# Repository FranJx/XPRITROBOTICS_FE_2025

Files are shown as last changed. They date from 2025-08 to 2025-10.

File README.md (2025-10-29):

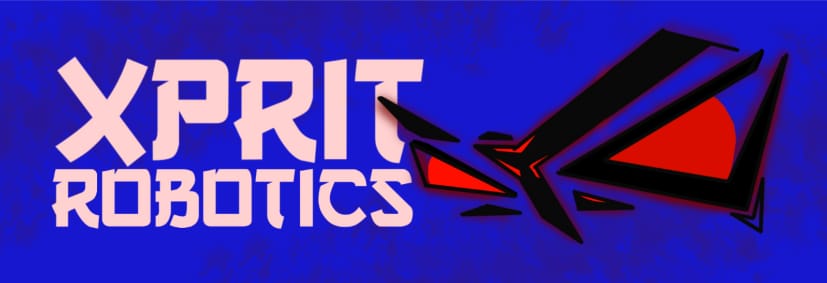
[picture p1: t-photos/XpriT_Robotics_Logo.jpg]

# - XpriT Robotics – WRO 2025 Future Engineers
## Introduction

We are **XpriT Robotics**, a team dedicated to creating robotics projects for participation in various competitions. Our main focus is on education and knowledge sharing, using challenges as opportunities to grow and inspire others. 
Through our projects, we explore robotics and engineering challenges to expand our skills, creativity, and experience.
For this competition, we aim to design a robot capable of avoiding obstacles, completing a circuit, and parking in a designated area.

This repository contains the engineering materials of our autonomous vehicle model developed by **XpriT Robotics**, competing in the **WRO 2025 Future Engineers** category. It includes source code, documentation, design files, photos, schematics, and a driving demonstration video.
---
## Repository Structure

* [**Bill Of Materials**](#bill-of-materials) - Bill Of all the Materials we used in this project covering mechanical pieces, 3D printed pieces, components and electronics.
* [**Step by Step Asemble Guide**](#step-by-step-asemble-guide) – This section provides a step-by-step guide, covering everything from assembling the parts to uploading the code and configuring some of the components.
* [**Software and Code Explanation**](#software-and-code-explanation) – This section provides a step-by-step guide, covering everything from assembling the parts to uploading the code and configuring some of the components.
* [**Engineering Journal**](#engineering-journal) – A journal where describes the decisions we made along the project.
---
## Folders Content

* [**T-photos**](t-photos/) – Two team photos: a formal one and a funny group shot.
* [**R-photos**](r-photos/) – Six images of the vehicle: front, back, left, right, top, and bottom.
* [**Video**](Videos/) – A Video of the robot driving.
* [**Schemes**](Schemes/) – Electromechanical schematic diagrams showing how components connect. 
* [**3Dmodels**](3Dmodels/) – Files for 3D-printed pieces of the robot
* [**Code**](Code/) – Robot code for Arduino Nano
---
## Meet the Robot
We proudly present **Kmioncito**, our robot for the WRO Future Engineers 2025 challenge.  
Its name, derived from the Spanish word *“camioncito”* (“little truck”), reflects its compact, sturdy design and the friendly personality we associate with our creations.
Kmioncito represents the result of months of teamwork, testing, and design iteration — combining **3D-printed mechanics**, **intelligent electronics**, and **optimized software** for autonomous navigation and obstacle avoidance.
### Robot Pictures From All Angules

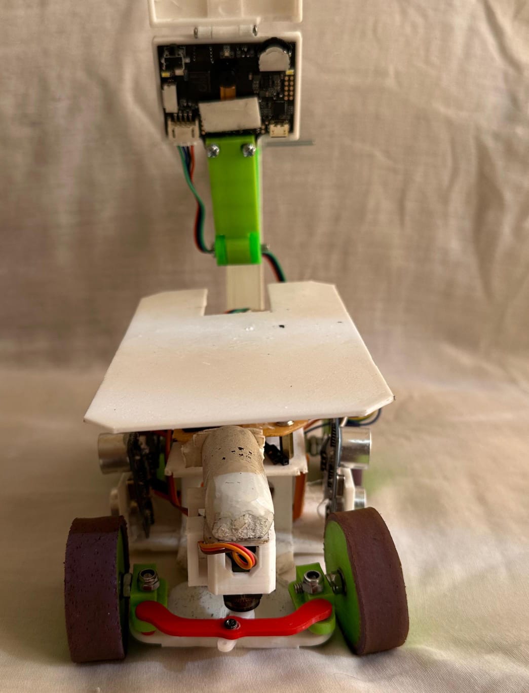
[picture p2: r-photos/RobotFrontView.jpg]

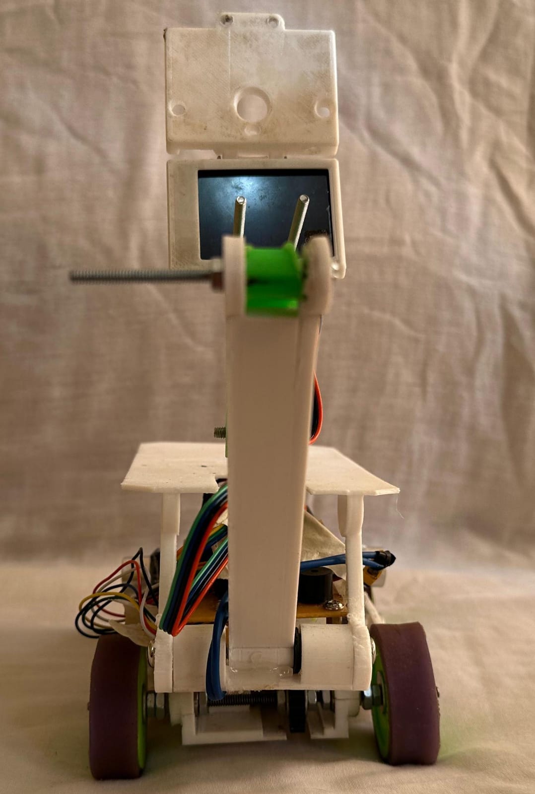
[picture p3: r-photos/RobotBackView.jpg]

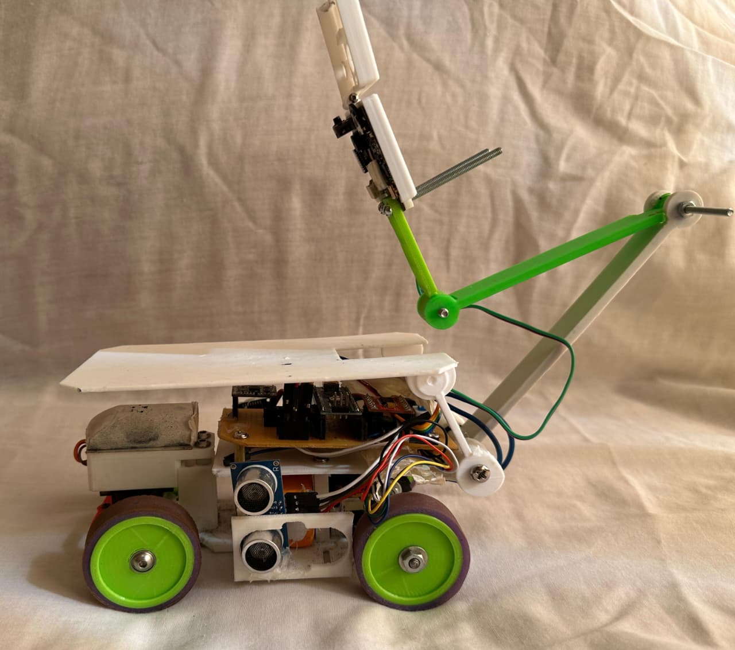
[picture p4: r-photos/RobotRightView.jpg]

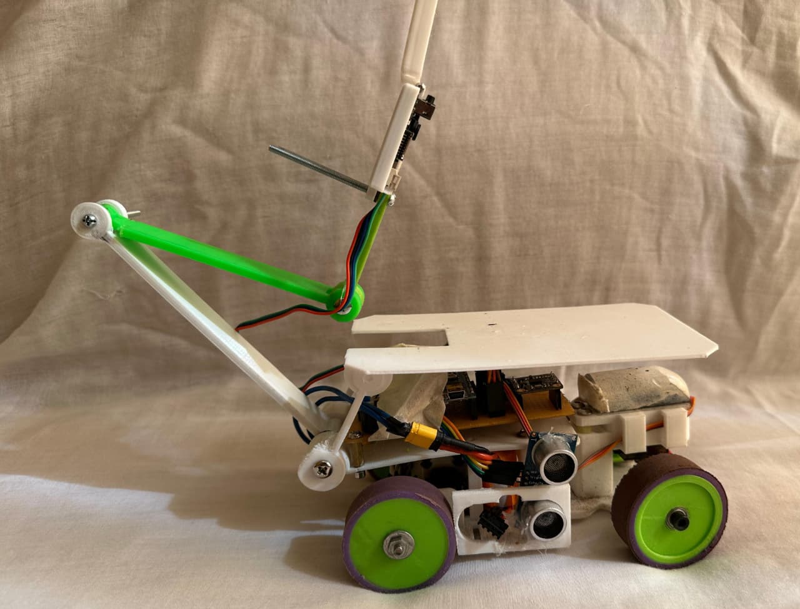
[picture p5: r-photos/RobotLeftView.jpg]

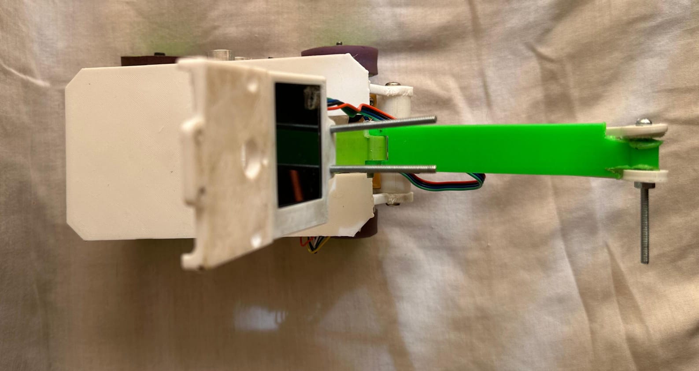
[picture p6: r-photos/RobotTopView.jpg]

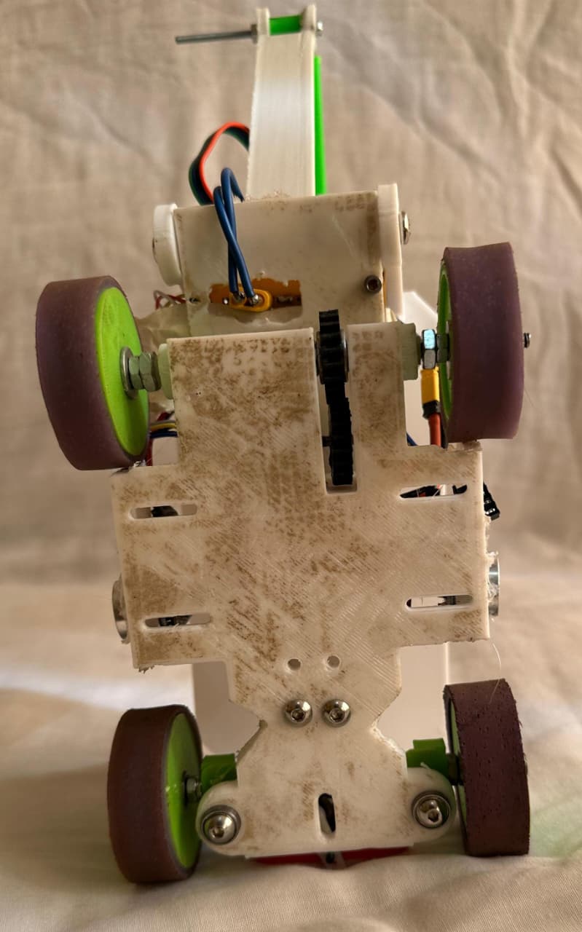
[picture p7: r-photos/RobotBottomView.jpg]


You can explore the mechanical, electronic, and software design in the sections below for detailed implementation.

---
## Bill Of Materials

### Electronics:
* 1x Arduino Nano. (Old Bootloader)
* 1x TB6612FNG
* 1x Diode
* 1x LN7805
* 1x Capacitor 100uf
* 1x Push Button
* 1x Push Interruptor
* 1x Active Buzzer

### Components and Sensors:
* 3x Ultrasonic Sensor HC-SR04
* 1x DFrobot Huskylens AI Camera
* 1x BNO055 gyroscope
* 1x MG90S servomotor
* 1x DC motor N20 with Encoder

### Mechanical and 3D printed Pieces:

* 6x Bearings (4mm interior and 10mm exterior)
* 8x Nuts
* 8x Washers
* 1x Threaded rod
* Every 3D model in the [**3Dmodels**](3Dmodels/) folder
---
## Project Overview

### Mechanical Design

The robot’s mechanical system was developed with a focus on **compactness, stability, and maneuverability**. It consists of two main subsystems: the **Ackermann steering mechanism** and the **traction system**.

#### Ackermann Steering System
- The steering is based on a simplified **Ackermann geometry**, implemented with a 3D-printed mechanism.  
- A **servo motor** (MG90S) controls the main steering linkage.  
- The linkage transmits motion to two pivoting axles, allowing the front wheels to turn at different angles during curves.  
- This ensures that the inner wheel follows a tighter turning radius than the outer wheel, improving maneuverability and reducing tire slip.  

**Advantages of this design:**
- Simple to manufacture with minimal mechanical parts.  
- Easy to assemble and maintain.  
- Lightweight, compact, and optimized for small turns within the competition field.  

#### Traction System
- The rear wheels are powered by **N20 DC motors with encoders**, providing both propulsion and feedback for precise distance control.  
- The motors transmit motion through a **1:1 gear ratio system**, using custom **resin-printed gears** mounted on a metal axle.  
- The axle drives both rear wheels simultaneously, ensuring consistent forward movement.  

**Advantages of this design:**
- High precision thanks to the encoders.  
- Strong and reliable traction for both straight paths and turns.  
- Custom gears in resin are resistant to wear compared to standard PLA 3D prints.  

#### Chassis
- The chassis is a **compact 3D-printed frame** with integrated mounts for electronics, sensors, and the steering system.  
- The design evolved from early modular prototypes to a single-piece chassis, reducing assembly complexity and improving robustness.  
- Includes a **dedicated adjustable mount for the HuskyLens camera**, allowing flexible positioning during testing and competition.  

### Electronics Design

The electronic system of the robot integrates all the sensors, actuators, and controllers required for autonomous navigation.  
A complete circuit schematic is included in the repository under the folder: [**Schematics**](Schematics/).

#### Microcontroller
- **Arduino Nano** serves as the main controller.  
- It processes sensor inputs, executes navigation algorithms, and controls actuators.  
- Connected via USB for programming and debugging.

#### Motor Driver
- **TB6612FNG dual motor driver**.  
- Used to drive the N20 DC motors with PWM speed control.  
- Provides reliable performance with low heat dissipation.

#### Motors and Actuators
- **2x N20 DC motors with encoders** (rear traction).  
- **1x MG90S servo motor** for the Ackermann steering mechanism.  
- Encoders provide feedback for distance and turning accuracy.

#### Sensors and Vision
- **2x HC-SR04 ultrasonic sensors** (left and right sides).  
  - Used for wall detection and corridor navigation.  
- **BNO055 IMU sensor**.  
  - Provides heading information for orientation correction and PID stabilization.  
- **HuskyLens AI Camera**.  
  - Detects obstacles (red and green cubes) and provides position data for avoidance maneuvers.  

#### Power Supply
- Powered by a **3S Li-Po battery (11.1V)**.  
- Voltage is regulated to supply 5V for the Arduino and sensors, and motor driver receives direct battery voltage.  
- Common ground is shared across all components.

#### Additional Components
- **Buzzer** connected to the Arduino, used as a feedback indicator for distance readings
---
## Step-by-Step Assembly Guide

This section provides a detailed guide on how to assemble the robot, from the mechanical systems to the electronics, camera setup, and software configuration.  

### 1. Steering System
**Required parts:** `Lower Chassis`, `Left Joint`, `Right Joint`, `Tires`, `Steering Axle`

1. Insert a bearing into each circular slot located at the front ends of the `Lower Chassis`.  
2. Place the `Left Joint` and `Right Joint` on top of the bearings, aligning them correctly with their sides.  
3. From the bottom, insert a screw through the bearing and secure it with a nut on top.  
4. Attach the `Tires` to the joints by inserting their axles into the wheel slot of each joint.  
5. Insert a screw through each wheel and joint, then fasten it with a nut on the opposite side. Repeat for both wheels.  
6. Mount the `Steering Axle` across the front of the joints, pressing it into the designated holes so it fits securely.  

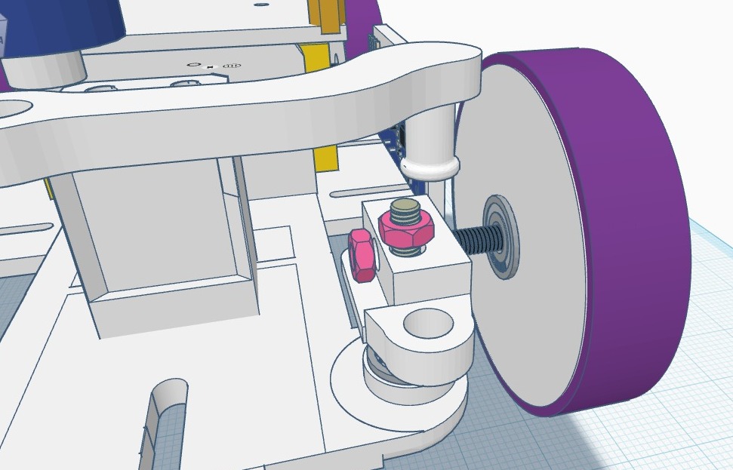
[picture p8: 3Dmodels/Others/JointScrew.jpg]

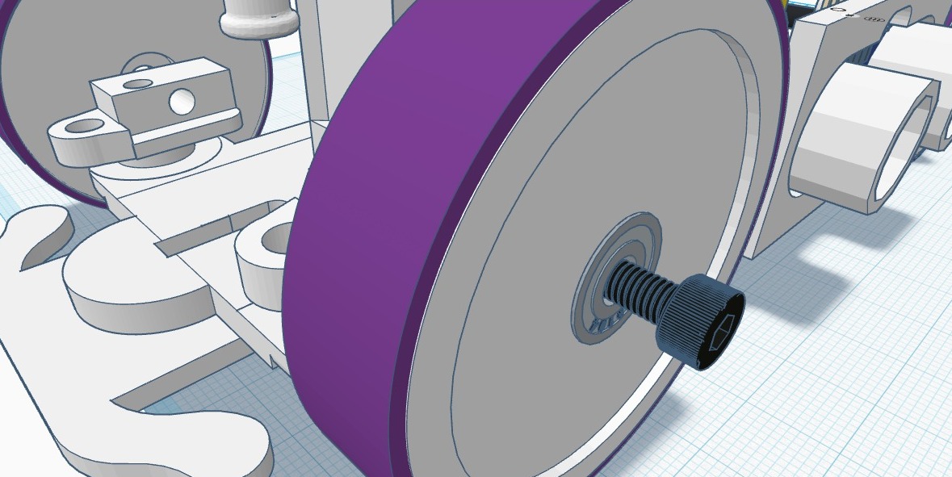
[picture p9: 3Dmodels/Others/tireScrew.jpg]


---

### 2. Servo Motor
**Required parts:** `Servo Motor Base`, `Servo Motor Holder`  

1. Place the `Servo Motor Base` slightly behind the steering system, aligning it with the four mounting holes in the chassis.  
2. Insert screws from the bottom of the chassis and secure them with nuts.  
3. Place the servo motor on top of the base.  
4. Fix it in place by mounting the `Servo Motor Holder` above it.  
5. Ensure the servo arm is aligned with the small hole at the center of the `Steering Axle`. Secure it with a screw.  

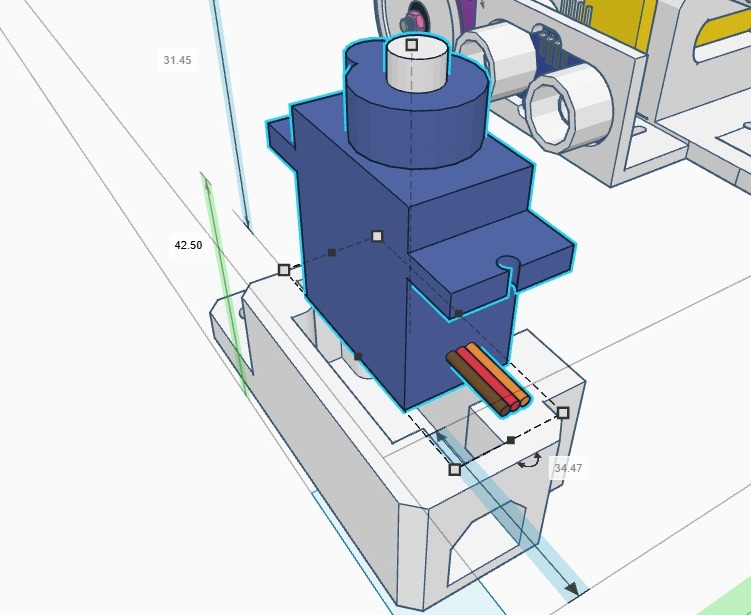
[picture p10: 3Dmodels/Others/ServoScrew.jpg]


---

### 3. Traction System
**Required parts:** `Rear Axle Gear`, `Motor Gear`, threaded rod, bearings, wheels, nuts and locknuts  

1. Locate the rear section of the chassis where the N20 motor mount and elongated slot are positioned.  
2. Mount the N20 motor into its slot and attach the `Motor Gear` to its shaft.  
3. Insert a bearing into each side wall hole of the chassis, pressing them firmly.  
4. Slide the threaded rod through the first bearing.  
5. Mount the `Rear Axle Gear` on the rod, then slide the rod through the second bearing. Both ends should extend slightly outside the chassis.  
6. Place a nut and a locknut on each side of the rod to secure it.  
7. Attach the wheels on both ends of the rod, leaving a small part of the rod exposed. Fix them with an additional nut on each side.  
8. Make sure the `Motor Gear` and the `Rear Axle Gear` are properly aligned so the motor can drive the axle.  

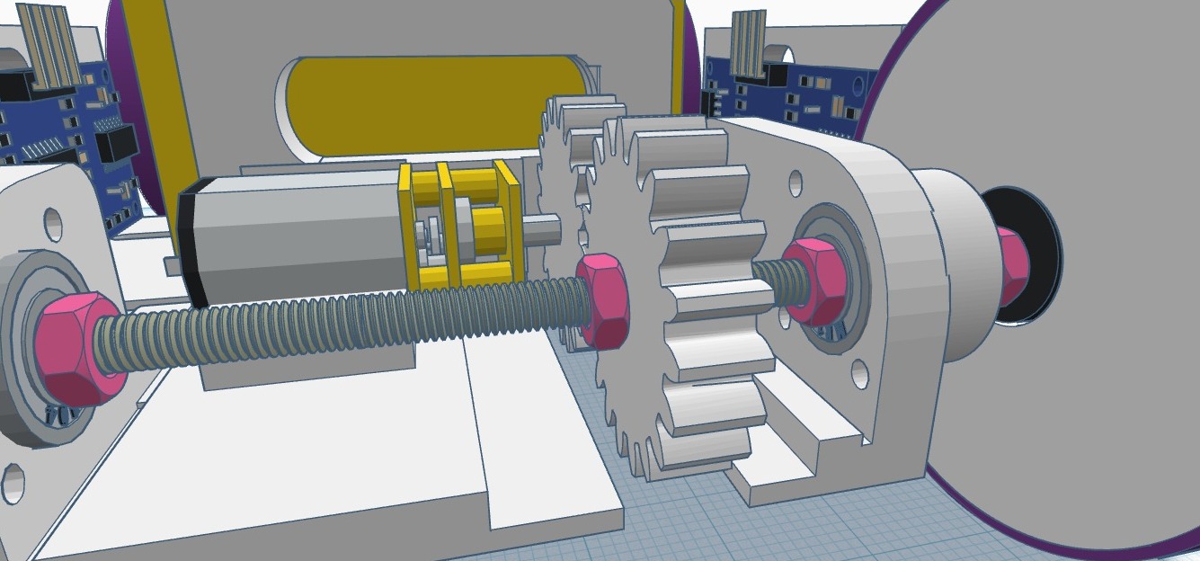
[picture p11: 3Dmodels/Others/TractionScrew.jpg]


---

### 4. Electronics
**Required part:** `Upper Chassis`  

1. Place the `Upper Chassis` above the main chassis, aligning its screw holes with the rectangular pillars.  
2. Secure it with screws and nuts.  
3. Mount the perforated PCB board on top of the `Upper Chassis`.  
4. Position the battery between the two lower pillars, underneath the PCB board.  

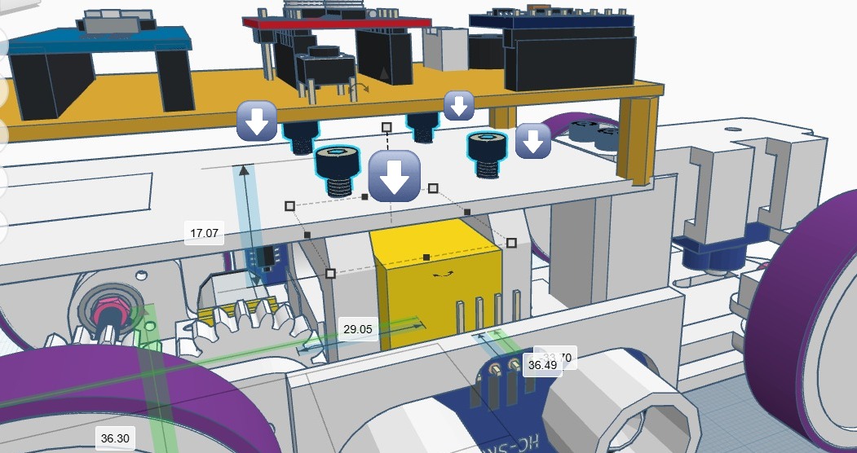
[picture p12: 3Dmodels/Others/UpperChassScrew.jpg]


---

### 5. Camera Support
**Required parts:** `PCB Ceiling`, `Lower Arm`, `Upper Arm`, `Camera Support`  

1. Attach the `PCB Ceiling` by aligning its arms with the `Upper Chassis`.  
2. Mount the `Lower Arm` in the middle and fasten it with screws.  
3. Connect the `Upper Arm` to the end of the `Lower Arm` and secure it.  
4. Attach the `Camera Support` at the end of the arm.  
5. Place the **HuskyLens camera** onto the support and secure it with screws.  


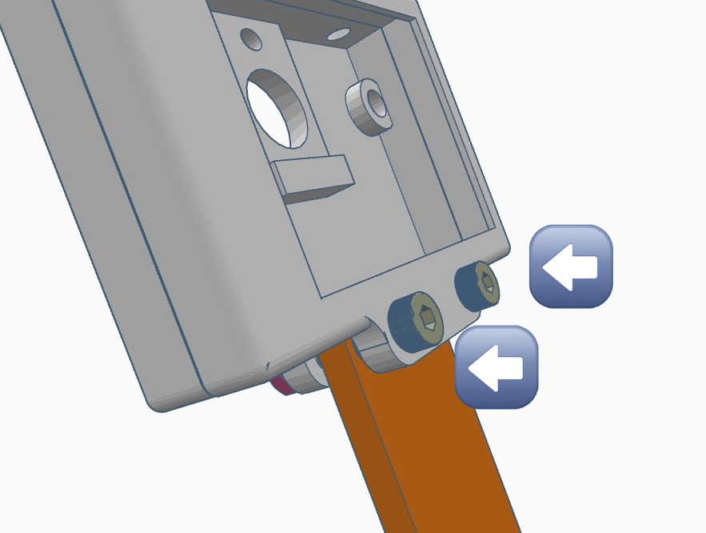
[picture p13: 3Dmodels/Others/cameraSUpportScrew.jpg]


---

### 6. Uploading the Code

1. Connect the **Arduino Nano** to your computer using a USB Mini-B cable.  
2. Open the **Arduino IDE** and load the provided code from this repository.  
3. Click **Upload** and wait until the IDE confirms `Upload complete`.  
4. Disconnect the cable after uploading.  

---

### 7. HuskyLens Configuration

1. Power on the robot (via battery or USB). The HuskyLens display will turn on.  
2. Use the dial to navigate through the HuskyLens interface.  
3. Go to **Settings → Communication Mode** and select **I2C**.  
4. Return to the main menu and select **Color Recognition** mode.  
5. Place the green and red obstacles in front of the camera.  
6. Hold the button next to the dial to train the color recognition.  
7. Repeat for both obstacles until the camera assigns **ID:1** to one color and **ID:2** to the other.  

---

At this point, your robot is fully assembled, configured, and ready for testing.

## Software and Code Explanation

The robot’s code was designed to combine stability, reliability, and adaptability during the challenge. Its behavior can be summarized in four main stages:
Straight Navigation with Gyroscope Correction

The robot advances forward while continuously correcting its heading using the BNO055 gyroscope. If it drifts from the desired orientation, the servo adjusts to bring it back on course, ensuring consistent straight-line movement.

### Corridor Turns with Ultrasonic Sensors

When one of the ultrasonic sensors detects open space to the left or right, the robot executes a precise 90° turn in that direction. The encoder ensures that the turn is completed fully by measuring wheel pulses, preventing incomplete or unstable turns.

### Object Avoidance with Vision (HuskyLens)

If the HuskyLens camera detects a red or green cube, the robot immediately prioritizes avoidance. It steers away from the object’s position and moves forward until the obstacle is no longer detected. Once clear, it recenters the servo and resumes its planned trajectory.

### Parking

At the beginning of the run, Kmioncito starts inside the parking area.  
Using the HuskyLens AI camera, it scans the first quadrant of its field of view to check if it can detect the pink color (ID:3) that represents the parking zone.  
Once the camera identifies this color, the robot determines its initial position and exits the parking area by moving toward the opposite direction of the detected wall.

As the robot leaves the zone, it uses its motor encoder to measure the distance traveled.  
If the distance exceeds one meter, the robot concludes that the parking zone is located at the rear side of the circuit.  
If it travels less than one meter, the robot determines that the parking zone is at the front side.  
This information is saved as a reference variable for the final part of the challenge.

After this step, Kmioncito continues its normal navigation, avoiding obstacles and following the circuit path.  
It ignores the parking area until the final stage of the run.

When it is time to park, the robot recalls the previously stored information about whether the parking zone is in the front or rear part of the field.  
It then moves toward that area, aligning its rear side with the front edge of the parking zone.  
Once aligned, it performs a 90° turn to face the parking area and starts reversing.  
While moving backward, the robot uses its ultrasonic sensors to detect the wall behind it.  
As soon as the wall is detected, it moves slightly forward, performs another 90° turn, and finally positions itself parallel to the wall, completing the parking maneuver.

### Completion of the Route

After a predefined number of turns, the robot drives forward for an additional encoder-based distance and then stops completely. This guarantees that the robot finishes the run in a controlled and repeatable manner.

---
## Engineering Journal

Here's a link to our Engineering Journal: 

https://docs.google.com/document/d/1Jj0EOl-bdzsbxWS2QZuM9kGpr0p5ontHu1RqVm_BO6E/edit?usp=sharing
---
## Demonstration Videos

https://youtu.be/O4qihtPzeu4?si=GkjUZdUodrYpeQK6
---

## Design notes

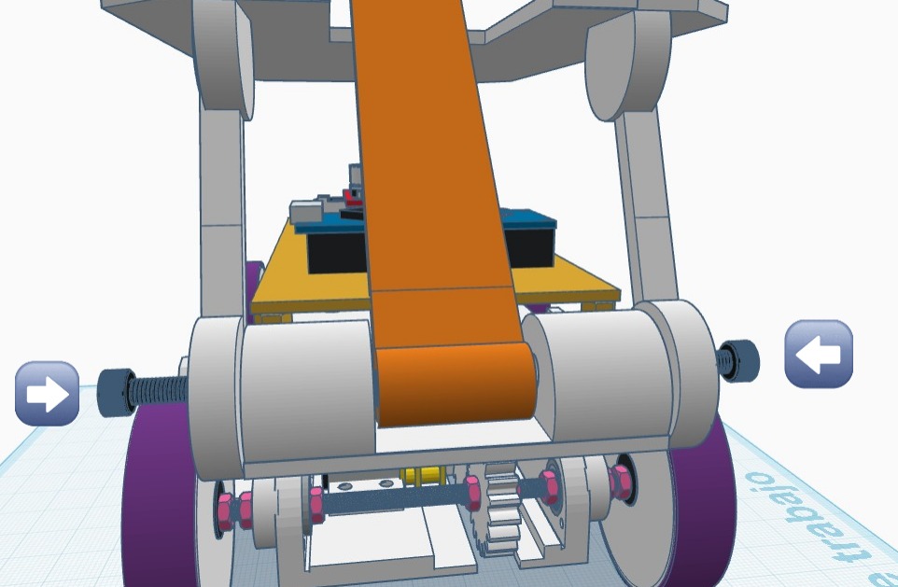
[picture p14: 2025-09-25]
3Dmodels/Others/pcb ceiling screw.jpg

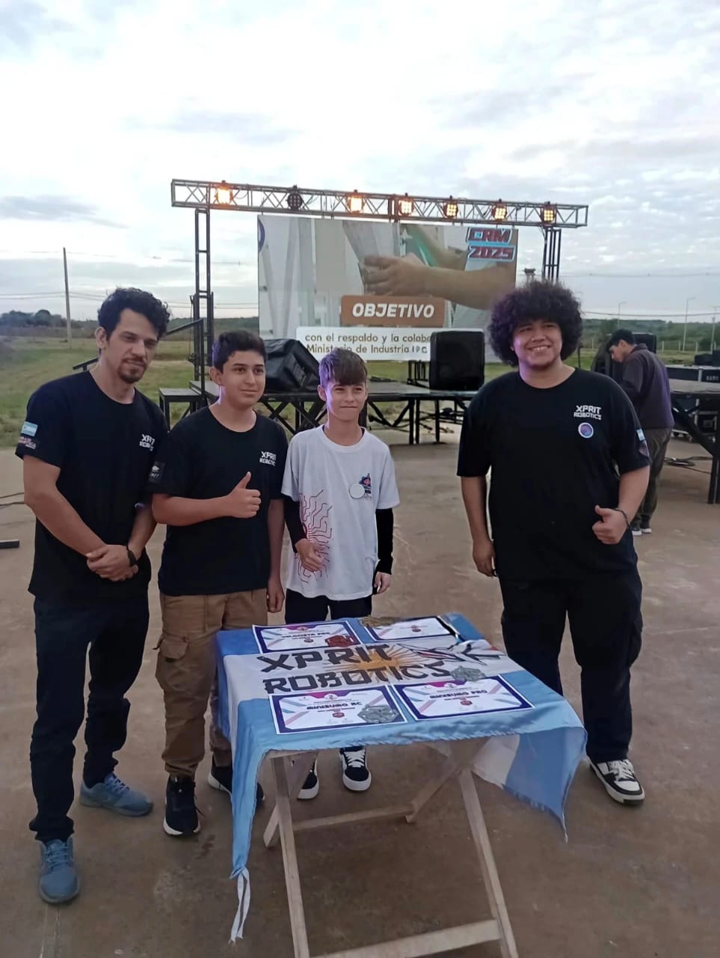
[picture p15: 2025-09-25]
t-photos/Imagen de WhatsApp 2025-09-25 a las 15.16.17_4187245f.jpg

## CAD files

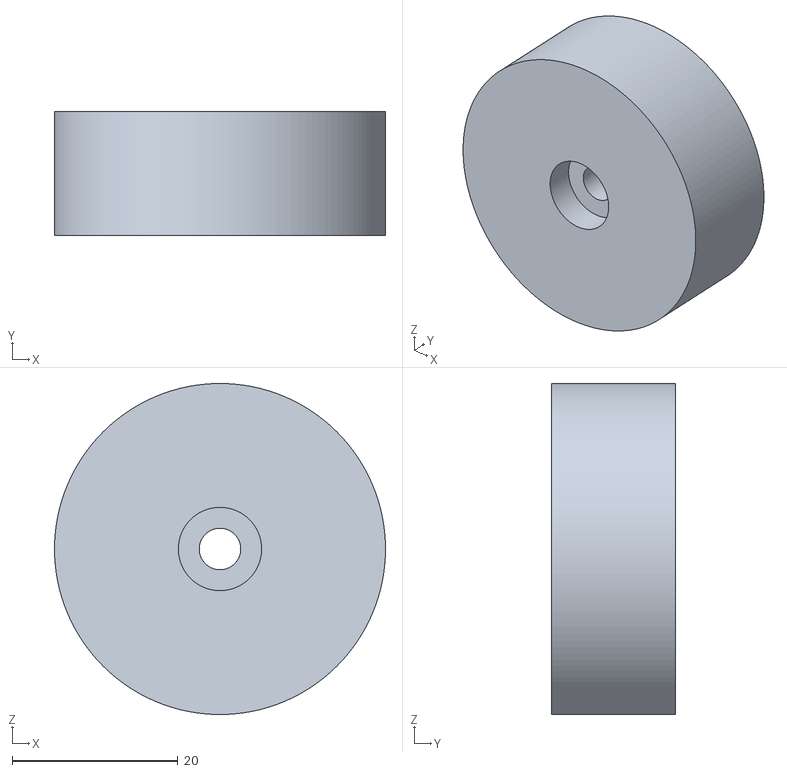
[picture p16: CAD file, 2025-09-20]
3Dmodels/rinx4.stl
40.0 x 15.0 x 40.0

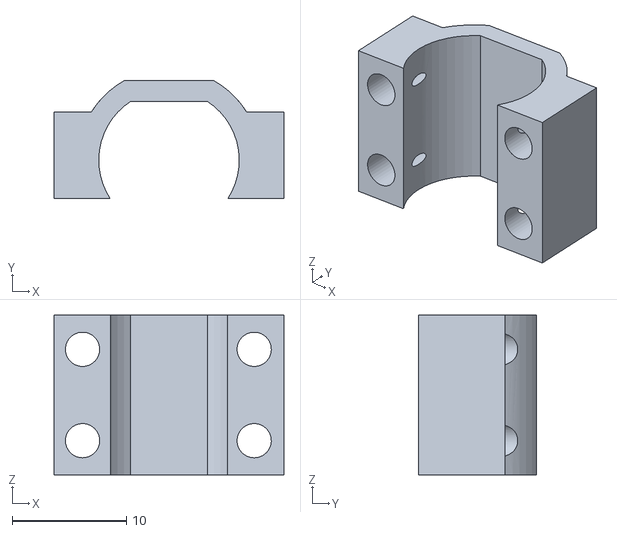
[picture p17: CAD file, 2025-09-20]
3Dmodels/bracket n20.STL
20.1 x 10.4 x 14.0

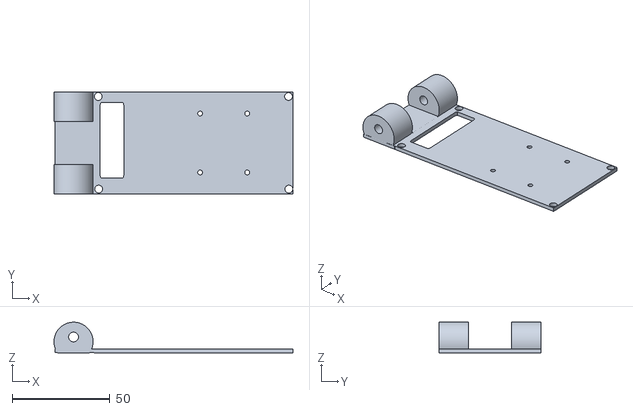
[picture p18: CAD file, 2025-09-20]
3Dmodels/soporte placa y cam.stl
122.4 x 52.2 x 15.7

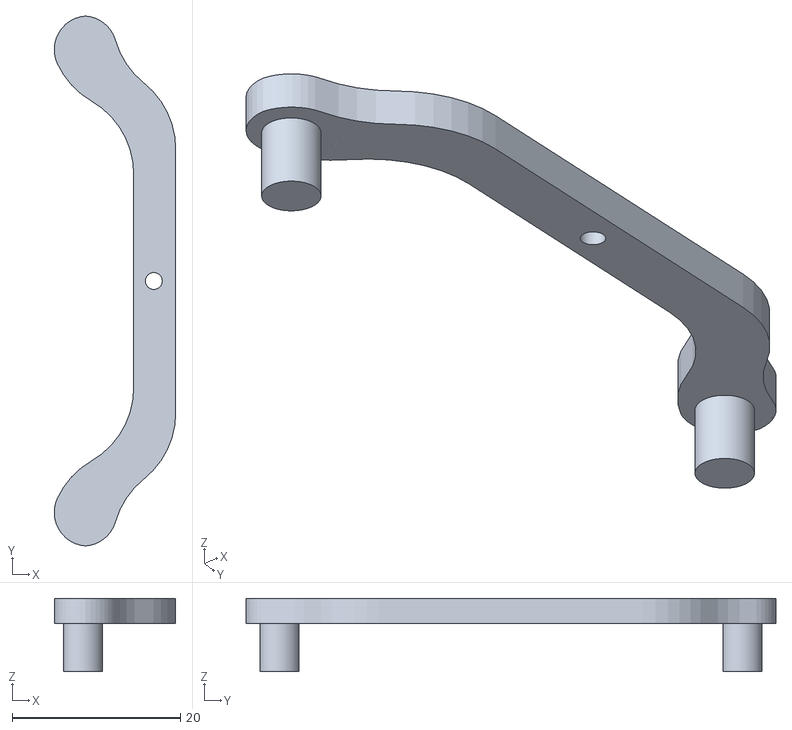
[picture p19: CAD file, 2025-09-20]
3Dmodels/cremallera.stl
14.4 x 63.0 x 8.70

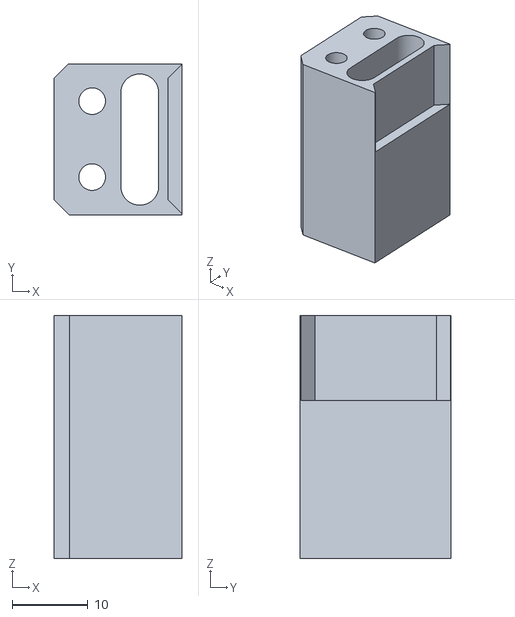
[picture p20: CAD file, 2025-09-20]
3Dmodels/Sizzling Rottis (6).stl
16.8 x 19.9 x 32.0

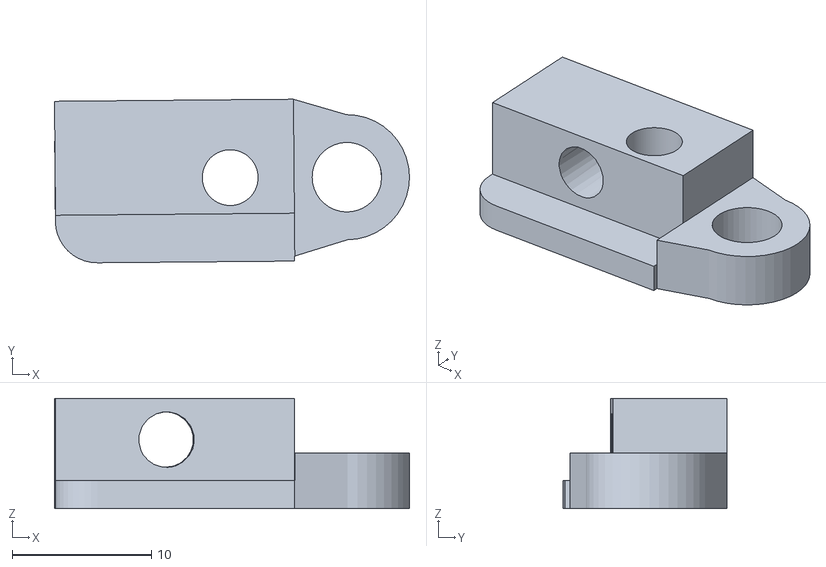
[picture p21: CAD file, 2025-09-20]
3Dmodels/rotulas (1).stl
25.5 x 11.8 x 7.91

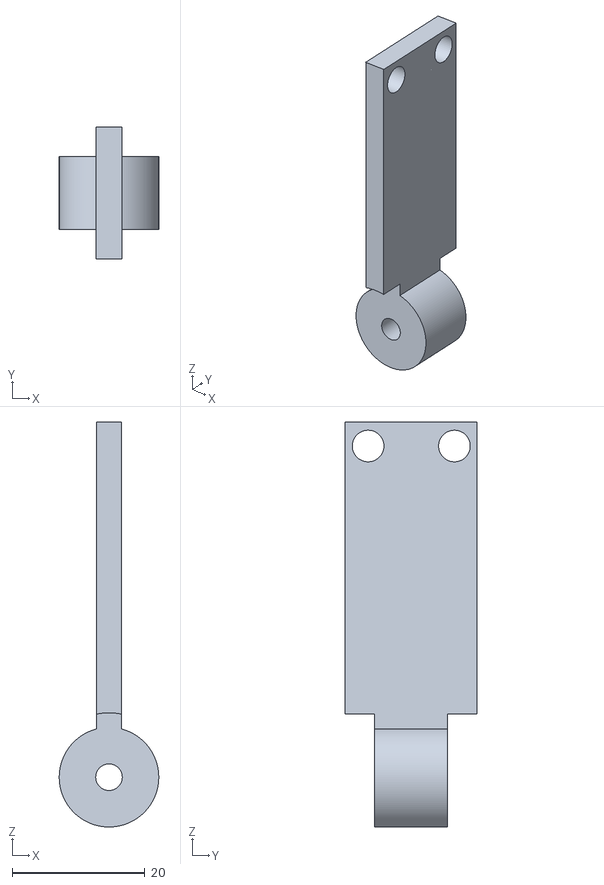
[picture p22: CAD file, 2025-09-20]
3Dmodels/brazocamsup.stl
15.0 x 19.9 x 61.0

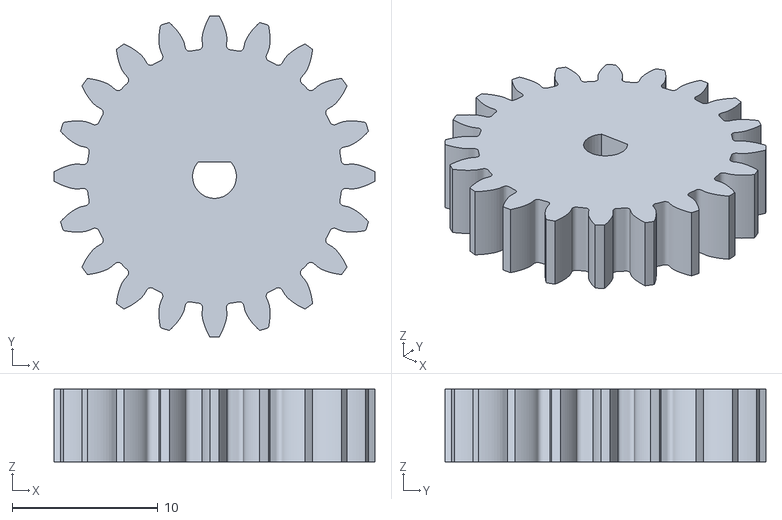
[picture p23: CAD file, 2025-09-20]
3Dmodels/engranajemotor.stl
22.0 x 22.0 x 5.00

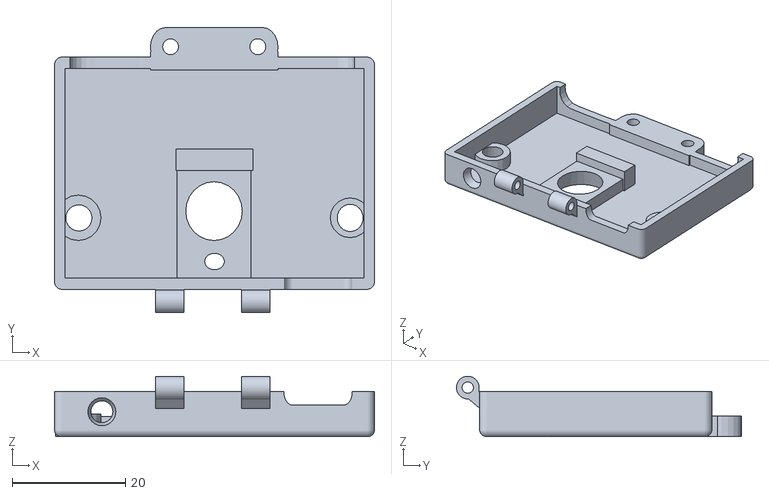
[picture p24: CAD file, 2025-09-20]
3Dmodels/Huskylens Cover_front.stl
56.4 x 50.2 x 10.7

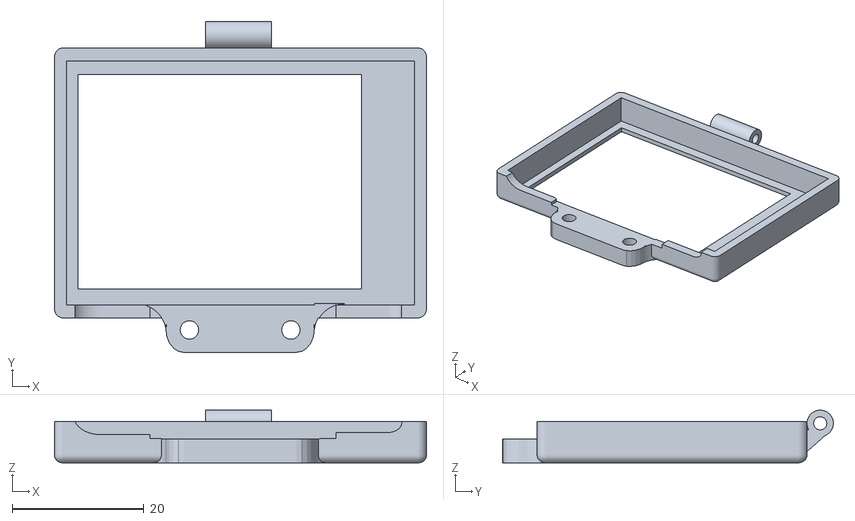
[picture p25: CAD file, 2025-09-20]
3Dmodels/Huskylens Cover_back.stl
56.4 x 50.1 x 8.00

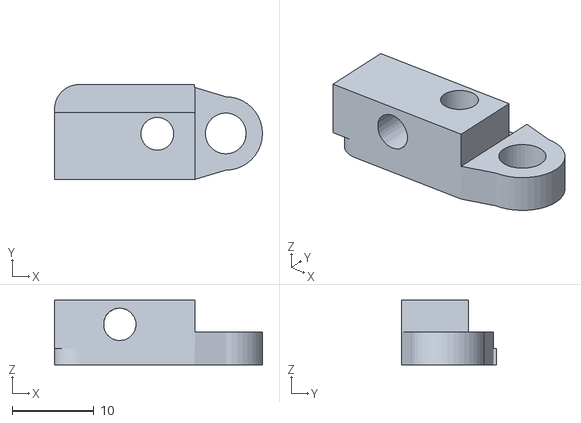
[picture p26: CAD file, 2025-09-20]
3Dmodels/rotulas (2).stl
25.5 x 11.6 x 7.91

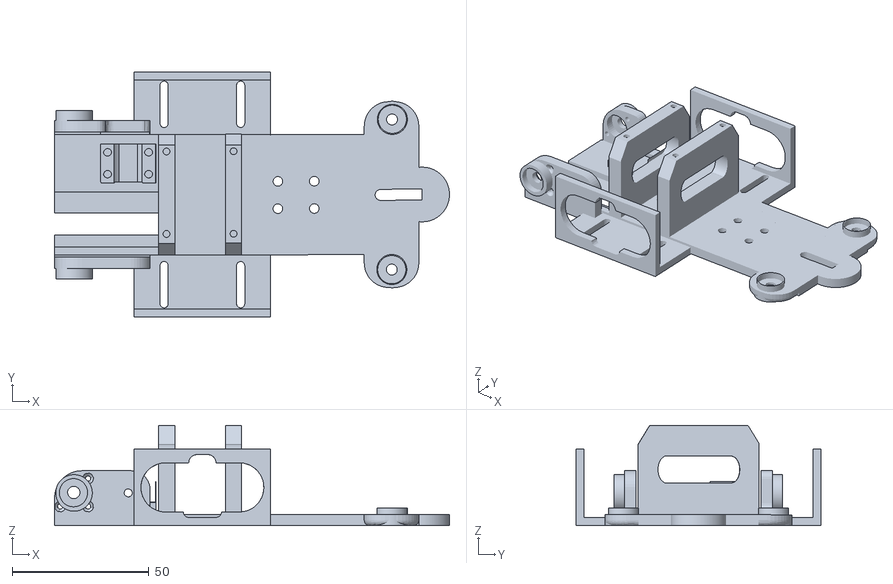
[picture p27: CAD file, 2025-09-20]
3Dmodels/chasis (2).stl
144.5 x 89.6 x 36.7

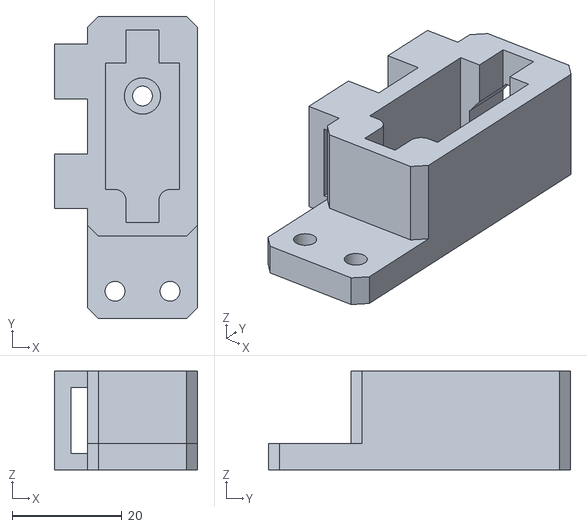
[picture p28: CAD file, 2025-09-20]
3Dmodels/servo_hold_bottom_1_lineguide.stl
26.0 x 55.0 x 18.0

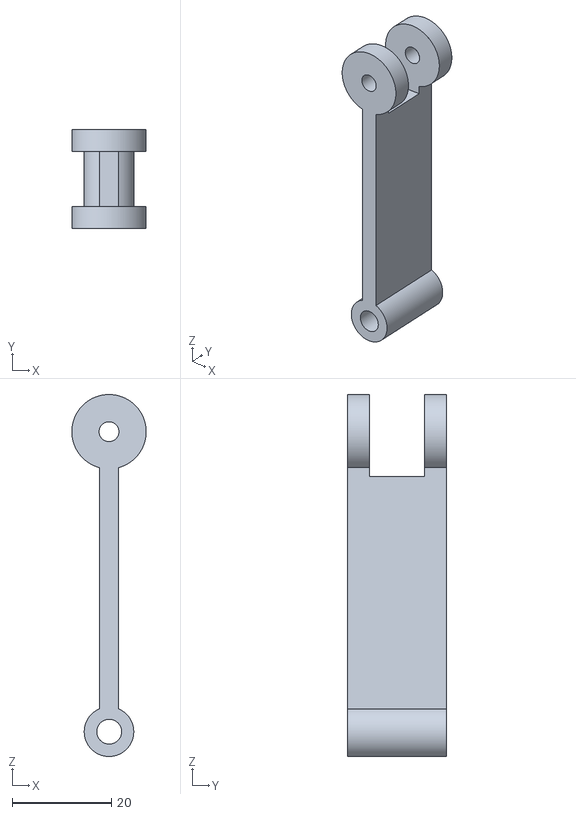
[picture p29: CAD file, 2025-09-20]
3Dmodels/brazocam inf.stl
15.0 x 20.0 x 73.0

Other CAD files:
3Dmodels/engranajeeje.stl

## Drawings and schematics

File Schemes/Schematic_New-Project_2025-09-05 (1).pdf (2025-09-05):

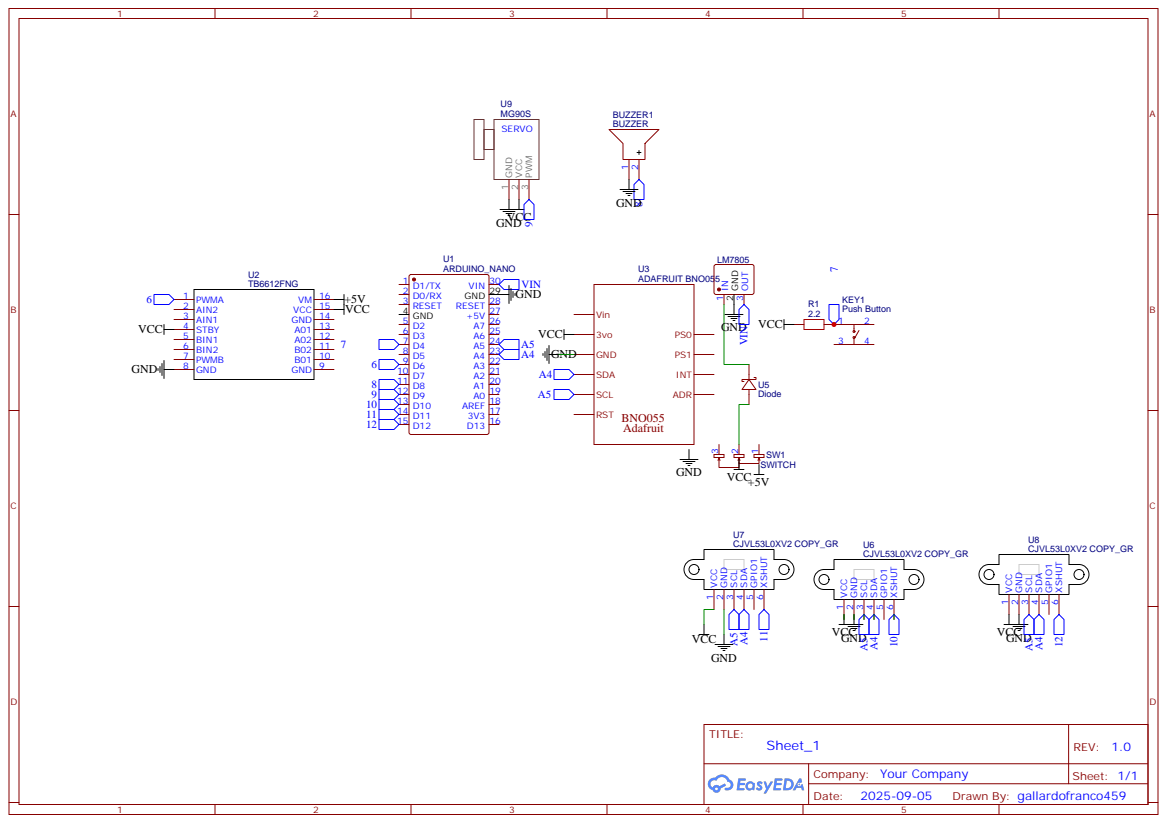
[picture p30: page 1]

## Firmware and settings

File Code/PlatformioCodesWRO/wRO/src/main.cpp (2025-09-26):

#include <Arduino.h>
#include <Servo.h>
#include <Adafruit_Sensor.h>

#include <Adafruit_BNO055.h>
#include <Wire.h>
#include "huskylens_utils.h"

#define TRIG_IZQ A2
#define ECHO_IZQ A3
#define TRIG_DER A0
#define ECHO_DER A1
#define MA1 5
#define MA2 4
#define PWM 6
#define SERVO_PIN 9
#define ENCODER_A 3

Servo direccion;
Adafruit_BNO055 bno = Adafruit_BNO055(55);
float Kp = 2.1, Ki = 0.0, Kd = 0.80;
int centroServo = 90;
int limAng = 50;
const int pwmRecto = 93;
const int pwmEsquiva = 120; // Velocidad especial al esquivar (ajusta a gusto)
const int pwmGiro = 165;
const int giros = 12;
int girosActuales = 0;
bool avanzandoExtra = false;
long encoderFinalExtra = 0;
const long PULSOS_EXTRA = 1000; // Pulsos extra tras el último giro
int lado = 0; // 0 = no definido, 1 = izquierda, 2 = derecha
const int distGiro = 30; // Distancia mínima para girar (cm)

bool velocidadVariable = false; // Si es false, siempre usa velocidad crucero
const int velocidadCrucero = 120; // 130    Ajusta este valor según tu necesidad
bool velocidadProporcionalServo = true; // NUEVO: Flag para velocidad proporcional al giro del servo
const int velocidadMinCrucero = 40;     //  52    Velocidad mínima en modo crucero proporcional

volatile long encoderCount = 0;
int orientation = 0;
float setpoint = 0;
bool bloqueado = false;
long pulsosBloqueo = 0;
int pulsosBloqueoUsar = 700;
const long PULSOS_GIRO = 900; // Bloqueo normal
const long PULSOS_GIRO_ESQUIVA = 1800; // Bloqueo si esquivó antes del giro
long ultimoEsquivaEncoder = -10000; // Para registrar el último encoder de esquiva
const long PASOS_ANTES_GIRO = 500;

long medirDistancia(int trigPin, int echoPin) {
  digitalWrite(trigPin, LOW);
  delayMicroseconds(2);
  digitalWrite(trigPin, HIGH);
  delayMicroseconds(10);
  digitalWrite(trigPin, LOW);
  long duracion = pulseIn(echoPin, HIGH, 25000);
  long distancia = duracion * 0.017;
  if (distancia == 0) distancia = 4000;
  return distancia;
}

void encoderISR() {
  encoderCount++;
}

void bloquearHeading(long pulsos) {
  bloqueado = true;
  pulsosBloqueo = encoderCount + pulsos;
}

void actualizarOrientation(int delta) {
  orientation += delta;
  if (orientation < 0) orientation = 3;
  if (orientation > 3) orientation = 0;
  setpoint = orientation * 90;
  bloquearHeading(pulsosBloqueoUsar);
}

void setup() {
  pinMode(8, OUTPUT); // buzzer
  Serial.begin(9200);
  pinMode(MA1, OUTPUT);
  pinMode(MA2, OUTPUT);
  pinMode(PWM, OUTPUT);
  pinMode(ENCODER_A, INPUT_PULLUP);
  direccion.attach(SERVO_PIN);
  direccion.write(90);
  delay(500);
  direccion.write(centroServo);
  attachInterrupt(digitalPinToInterrupt(ENCODER_A), encoderISR, RISING);
  if (!bno.begin()) {
    Serial.println("No se detecta BNO055");
    while (1);
  }
  bno.setExtCrystalUse(true);
  pinMode(TRIG_IZQ, OUTPUT);
  pinMode(ECHO_IZQ, INPUT);
  pinMode(TRIG_DER, OUTPUT);
  pinMode(ECHO_DER, INPUT);
  sensors_event_t event;
  bno.getEvent(&event);
  setpoint = event.orientation.x;
  orientation = 0;
  encoderCount = 0;
  bloqueado = false;
  delay(1000);
  // Inicializar HUSKYlens
  huskylens.beginI2CUntilSuccess();
}


// --- Lógica de esquiva con HUSKYlens ---
bool esquivando = false;
bool prioridadEsquiva = false; // Flag para prioridad de esquiva
int objetoEsquivando = 0; // 0 = nada, 1 = id1, 2 = id2
bool giroPendiente = false; // Nuevo: indica si hay un giro pendiente tras esquiva

// Parámetros para PID de esquiva y ROI
const int ROI_X_MIN = 80;   // Límite izquierdo del ROI (ajustar según resolución HUSKYlens)
const int ROI_X_MAX = 290;  // Límite derecho del ROI
const int MIN_BLOQUE_ANCHO = 25; // Tamaño mínimo de bloque para considerar esquiva
const int MIN_BLOQUE_ALTO = 45;
const int MAX_BLOQUE_ANCHO = 960; // Límite máximo de ancho para considerar esquiva
const int MAX_BLOQUE_ALTO = 9400;  // Límite máximo de alto para considerar esquiva
float Kp_husky = 0.9, Ki_husky = 0.0, Kd_husky = 1.0;
static float integral_husky = 0, last_error_husky = 0;

bool fijarDireccionGiro = true; // Flag para activar esta lógica
int direccionGiroFijada = 0;    // 0: no fijada, -1: izquierda, 1: derecha

bool esperandoPared = false;
int paredEsperada = 0; // -1 = izquierda, 1 = derecha, 0 = ninguna
const int UMBRAL_PARED = 80; // cm, ajusta según tu entorno
unsigned long paredDetectadaDesde = 0;
const unsigned long TIEMPO_PARED_MIN = 1100; // ms, tiempo mínimo para validar pared

void loop() {
  // Calcular error de heading y bloqueo general (después de definir heading)
  
  sensors_event_t event;
  bno.getEvent(&event);
  float heading = event.orientation.x;
  long distIzq = medirDistancia(TRIG_IZQ, ECHO_IZQ);
  long distDer = medirDistancia(TRIG_DER, ECHO_DER);
  float errorHeading = heading - setpoint;
  if (errorHeading > 180) errorHeading -= 360;
  if (errorHeading < -180) errorHeading += 360;
  bool bloqueoHeadingGeneral = abs(errorHeading) > 17;
  // Buzzer
  if (distIzq > 200 || distDer > 200) {
    tone(8, 5000, 10);
  } else if (distIzq > 90 || distDer > 90) {
    tone(8, 1500, 10);
  }

  // --- Lógica de esquiva con HUSKYlens: si ve bloque id1 o id2 mayor a 10x10, girar ---
  huskylens.request();
  bool bloque_valido = false;
  int id_detectado = 0;
  int x_bloque = 0, y_bloque = 0, w_bloque = 0, h_bloque = 0;
  int max_area = 0;
  for (int id = 1; id <= 2; id++) {
    if (huskylens.isAppear(id, HUSKYLENSResultBlock)) {
      HUSKYLENSBlockInfo bloque = huskylens.readBlockParameter(id);
      int area = bloque.width * bloque.height;
      // Nueva condición: descartar si el ancho es más de 2.5 veces el alto
      bool proporcionValida = (bloque.width <= 1.1 * bloque.height);
      if (bloque.width > MIN_BLOQUE_ANCHO && bloque.width <= MAX_BLOQUE_ANCHO &&
          bloque.height > MIN_BLOQUE_ALTO && bloque.height <= MAX_BLOQUE_ALTO &&
          area > max_area && proporcionValida) {
        bloque_valido = true;
        id_detectado = id;
        x_bloque = bloque.xCenter;
        y_bloque = bloque.yCenter;
        w_bloque = bloque.width;
        h_bloque = bloque.height;
        max_area = area;
      }
    }
  }

  if (bloque_valido) {
    prioridadEsquiva = true;
    ultimoEsquivaEncoder = encoderCount;
    // Si está bloqueado por giro, marcar giro pendiente
    if (bloqueado) {
      giroPendiente = true;
      bloqueado = false; // Interrumpe el giro para esquivar
    }
    // Corrección FIJA según el lado
    int correction = 40; // Ajusta este valor para el ángulo de giro deseado
    if (id_detectado == 1) {
      // ID1: esquiva hacia la derecha
      direccion.write(centroServo - correction);
    } else if (id_detectado == 2) {
      // ID2: esquiva hacia la izquierda
      direccion.write(centroServo + correction);
    }
    // Limitar el ángulo para no exceder el rango seguro
    int servo_angle = direccion.read();
    if (servo_angle < centroServo - limAng) servo_angle = centroServo - limAng;
    if (servo_angle > centroServo + limAng) servo_angle = centroServo + limAng;
    direccion.write(servo_angle);
    esquivando = true;

    // --- Ajuste de velocidad de esquiva según ángulo del servo ---
    int velocidadEsquivaActual = pwmEsquiva;
    if (servo_angle >= 77 && servo_angle <= 103) {
      velocidadEsquivaActual = pwmEsquiva - 18;
      if (velocidadEsquivaActual < 0) velocidadEsquivaActual = 0;
    }

    int velocidadActual = velocidadCrucero;
    if (velocidadVariable) {
        velocidadActual = velocidadEsquivaActual;
    }
    analogWrite(PWM, velocidadActual);

    digitalWrite(MA1, HIGH);
    digitalWrite(MA2, LOW);
    Serial.print("HUSKYlens: ID="); Serial.print(id_detectado);
    Serial.print(" X="); Serial.print(x_bloque);
    Serial.print(" Y="); Serial.print(y_bloque);
    Serial.print(" W="); Serial.print(w_bloque);
    Serial.print(" H="); Serial.println(h_bloque);
    return;
  } else if (esquivando) {
    direccion.write(centroServo);
    esquivando = false;
    prioridadEsquiva = false;
    objetoEsquivando = 0;
    // Si había un giro pendiente, reactivar el bloqueo de heading
    if (giroPendiente) {
      bloquearHeading(pulsosBloqueoUsar);
      giroPendiente = false;
    }
  }

  // PID para mantener heading
  float error = heading - setpoint;
  if (error > 180) error -= 360;
  if (error < -180) error += 360;
  static float integral = 0, last_error = 0;
  integral += error;
  float derivative = error - last_error;
  float correction = Kp * error + Ki * integral + Kd * derivative;
  int servo_angle = centroServo - correction;
  if (servo_angle < centroServo - limAng) servo_angle = centroServo - limAng;
  if (servo_angle > centroServo + limAng) servo_angle = centroServo + limAng;
  direccion.write(servo_angle);
  last_error = error;

  // Avanzar motor: PWM depende de si está girando (bloqueado) o recto
  int velocidadActual = velocidadCrucero;
  if (velocidadVariable) {
    if (esquivando) {
        velocidadActual = pwmEsquiva;
    } else if (bloqueado) {
        velocidadActual = pwmGiro;
    } else {
        velocidadActual = pwmRecto;
    }
  }

  // NUEVO: velocidad proporcional al giro del servo en modo crucero
  if (!velocidadVariable && velocidadProporcionalServo) {
    int desviacion = abs(servo_angle - centroServo);
    // Cuanto más gire el servo, más rápido va (mínimo en recto, máximo en limAng)
    velocidadActual = velocidadMinCrucero + (velocidadCrucero - velocidadMinCrucero) * desviacion / limAng;
    if (velocidadActual > velocidadCrucero) velocidadActual = velocidadCrucero;
    if (velocidadActual < velocidadMinCrucero) velocidadActual = velocidadMinCrucero;
  }

  analogWrite(PWM, velocidadActual);
  digitalWrite(MA1, HIGH);
  digitalWrite(MA2, LOW);

  // Cambiar heading solo si no está bloqueado
  if (!bloqueado && !bloqueoHeadingGeneral && !prioridadEsquiva && !esperandoPared) {
  pulsosBloqueoUsar = PULSOS_GIRO;

  if (fijarDireccionGiro && direccionGiroFijada != 0) {
    if (direccionGiroFijada == -1 && distIzq > 75) {
      long distDerGiro = medirDistancia(TRIG_DER, ECHO_DER);
      pulsosBloqueoUsar = (distDerGiro < distGiro) ? 00 : 00;
      actualizarOrientation(-1);
      girosActuales++;
      if (girosActuales == giros) {
        avanzandoExtra = true;
        encoderFinalExtra = encoderCount + PULSOS_EXTRA;
      }
      // Esperar a que reaparezca la pared izquierda
      esperandoPared = true;
      paredEsperada = -1;
    } else if (direccionGiroFijada == 1 && distDer > 75) {
      long distIzqGiro = medirDistancia(TRIG_IZQ, ECHO_IZQ);
      pulsosBloqueoUsar = (distIzqGiro < distGiro) ? 00 : 00;
      actualizarOrientation(1);
      girosActuales++;
      if (girosActuales == giros) {
        avanzandoExtra = true;
        encoderFinalExtra = encoderCount + PULSOS_EXTRA;
      }
      // Esperar a que reaparezca la pared derecha
      esperandoPared = true;
      paredEsperada = 1;
    }
  } else {
    if (distIzq > 75) {
      long distDerGiro = medirDistancia(TRIG_DER, ECHO_DER);
      pulsosBloqueoUsar = (distDerGiro < distGiro) ? 0 : 0;
      actualizarOrientation(-1);
      girosActuales++;
      if (fijarDireccionGiro) direccionGiroFijada = -1;
      if (girosActuales == giros) {
        avanzandoExtra = true;
        encoderFinalExtra = encoderCount + PULSOS_EXTRA;
      }
      esperandoPared = true;
      paredEsperada = -1;
    } else if (distDer > 75) {
      long distIzqGiro = medirDistancia(TRIG_IZQ, ECHO_IZQ);
      pulsosBloqueoUsar = (distIzqGiro < distGiro) ? 0 : 0;
      actualizarOrientation(1);
      girosActuales++;
      if (fijarDireccionGiro) direccionGiroFijada = 1;
      if (girosActuales == giros) {
        avanzandoExtra = true;
        encoderFinalExtra = encoderCount + PULSOS_EXTRA;
      }
      esperandoPared = true;
      paredEsperada = 1;
    }
  }
  } else {
    float errorHeading = heading - setpoint;
    if (errorHeading > 180) errorHeading -= 360;
    if (errorHeading < -180) errorHeading += 360;
    if (encoderCount >= pulsosBloqueo && abs(errorHeading) < 15) {
      bloqueado = false;
    }
  }

  // Lógica para liberar el giro cuando la pared reaparece (con validación por tiempo)
  if (esperandoPared) {
    bool paredDetectada = false;
    if (paredEsperada == -1 && distIzq < UMBRAL_PARED) paredDetectada = true;
    if (paredEsperada == 1 && distDer < UMBRAL_PARED) paredDetectada = true;

    if (paredDetectada) {
      if (paredDetectadaDesde == 0) paredDetectadaDesde = millis();
      if (millis() - paredDetectadaDesde > TIEMPO_PARED_MIN) {
        esperandoPared = false;
        paredEsperada = 0;
        paredDetectadaDesde = 0;
      }
    } else {
      paredDetectadaDesde = 0; // Reinicia si deja de detectar la pared
    }
  }

  // (Opcional) imprimir estado por Serial
  Serial.print("Heading: "); Serial.print(heading);
  Serial.print(" | Setpoint: "); Serial.print(setpoint);
  Serial.print(" | Orientation: "); Serial.print(orientation);
  Serial.print(" | Encoder: "); Serial.print(encoderCount);
  Serial.print(" | US Izq: "); Serial.print(distIzq);
  Serial.print(" | US Der: "); Serial.println(distDer);
  if (avanzandoExtra) {
    if (encoderCount >= encoderFinalExtra) {
      Serial.println("Avance extra completado. Deteniendo.");
      digitalWrite(MA1, LOW);
      digitalWrite(MA2, LOW);
      while (1); // Detener el programa
    }
  } else if (girosActuales > giros) {
    Serial.println("Número máximo de giros alcanzado. Deteniendo.");
    digitalWrite(MA1, LOW);
    digitalWrite(MA2, LOW);
    while (1); // Detener el programa
  }
}

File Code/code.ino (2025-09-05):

#include <Arduino.h>
#include <Wire.h>
#include <Servo.h>
#include <Adafruit_Sensor.h>
#include <Adafruit_BNO055.h>
#include <VL53L0X.h>

// Pines del motor y encoder
#define MA1 5
#define MA2 4
#define PWM 6
#define ENCODER_A 3

// Servo y BNO055
#define SERVO_PIN 9

// Pines XSHUT
#define XSHUT_2 11
#define XSHUT_3 12

// Direcciones I2C nuevas
#define NEW_ADDRESS_1 0x30
#define NEW_ADDRESS_2 0x31
#define NEW_ADDRESS_3 0x32

// Parámetros del encoder y rueda
const float WHEEL_DIAMETER_MM = 35.0;
const float WHEEL_PERIMETER_MM = WHEEL_DIAMETER_MM * 3.1416;
const int ENCODER_PULSES_PER_REV = 420;
const float PULSES_PER_MM = ENCODER_PULSES_PER_REV / WHEEL_PERIMETER_MM;
const int DIST_MM = 450; // 10 cm aprox
const int TARGET_PULSES = PULSES_PER_MM * DIST_MM;

// PID parámetros
float Kp = 0.9;
float Ki = 0.0;
float Kd = 1.0;

volatile long encoderCount = 0;
Servo direccion;
Adafruit_BNO055 bno = Adafruit_BNO055(55);

VL53L0X sensor1; // Frontal
VL53L0X sensor2; // Izquierdo
VL53L0X sensor3; // Derecho

int distVL1 = 0;
int distVL2 = 0;
int distVL3 = 0;

int orientation = 0; // 0=North, 1=East, 2=South, 3=West
int facing = 0;      // orientation * 90

void encoderISR() {
  encoderCount++;
}

void setup() {
  Serial.begin(115200);
  pinMode(8, OUTPUT); // buzzer
  pinMode(MA1, OUTPUT);
  pinMode(MA2, OUTPUT);
  pinMode(PWM, OUTPUT);
  pinMode(ENCODER_A, INPUT_PULLUP);

  direccion.attach(SERVO_PIN);
  direccion.write(90); // Recto

  attachInterrupt(digitalPinToInterrupt(ENCODER_A), encoderISR, RISING);

  if (!bno.begin()) {
    Serial.println("No se detecta BNO055");
    while (1);
  }
  delay(1000);
  bno.setExtCrystalUse(true);

  Serial.println("Listo para control PID de direccion y motor");

  // Desactiva CS del SPI para evitar interferencias en I2C
  pinMode(10, OUTPUT);
  digitalWrite(10, HIGH);

  // Inicialización de sensores VL53L0X
  pinMode(XSHUT_2, OUTPUT);
  pinMode(XSHUT_3, OUTPUT);
  digitalWrite(XSHUT_2, LOW);
  digitalWrite(XSHUT_3, LOW);
  delay(10);

  Wire.begin();

  // Inicializa el primer sensor (sin XSHUT)
  Serial.println("Inicializando sensor 1...");
  if (!sensor1.init(true)) {
    Serial.println("Fallo al inicializar el sensor 1");
    while (1);
  }
  sensor1.setAddress(NEW_ADDRESS_1);
  Serial.print("Sensor 1 direccionado a 0x");
  Serial.println(NEW_ADDRESS_1, HEX);

  // Enciende el segundo sensor
  digitalWrite(XSHUT_2, HIGH);
  delay(10);

  // Inicializa el segundo sensor
  Serial.println("Inicializando sensor 2...");
  if (!sensor2.init(true)) {
    Serial.println("Fallo al inicializar el sensor 2");
    while (1);
  }
  sensor2.setAddress(NEW_ADDRESS_2);
  Serial.print("Sensor 2 direccionado a 0x");
  Serial.println(NEW_ADDRESS_2, HEX);

  // Enciende el tercer sensor
  digitalWrite(XSHUT_3, HIGH);
  delay(10);

  // Inicializa el tercer sensor
  Serial.println("Inicializando sensor 3...");
  if (!sensor3.init(true)) {
    Serial.println("Fallo al inicializar el sensor 3");
    while (1);
  }
  sensor3.setAddress(NEW_ADDRESS_3);
  Serial.print("Sensor 3 direccionado a 0x");
  Serial.println(NEW_ADDRESS_3, HEX);

  sensor1.startContinuous();
  sensor2.startContinuous();
  sensor3.startContinuous();
  delay(200);
  tone(8, 1500, 50);
  delay(70);
  tone(8, 1500, 50);
  delay(70);
}

void moveMotorPID(bool forward, int pulses) {
  encoderCount = 0;

  // Inicializa motor
  if (forward) {
    digitalWrite(MA1, HIGH);
    digitalWrite(MA2, LOW);
  } else {
    digitalWrite(MA1, LOW);
    digitalWrite(MA2, HIGH);
  }

  int maxPWM = 200;
  int minPWM = 80;

  // PID variables
  float setpoint = facing; // Heading objetivo
  float last_error = 0;
  float integral = 0;

  // Lee el heading inicial
  sensors_event_t event;
  bno.getEvent(&event);

  while (encoderCount < pulses) {
    // Lee heading actual
    bno.getEvent(&event);
    float heading = event.orientation.x;

    // Calcula error de heading (considera wrap-around 0-360)
    float error = heading - setpoint;
    if (error > 180) error -= 360;
    if (error < -180) error += 360;

    integral += error;
    float derivative = error - last_error;

    float correction = Kp * error + Ki * integral + Kd * derivative;

    // Corrige servo (90 es recto)
    int servo_angle = 85 - correction;
    if (servo_angle < 50) servo_angle = 50;
    if (servo_angle > 150) servo_angle = 150;
    direccion.write(servo_angle);

    // Control de velocidad proporcional a la distancia restante
    int error_dist = pulses - encoderCount;
    int pwmValue = 0.5 * error_dist;
    if (pwmValue > maxPWM) pwmValue = maxPWM;
    if (pwmValue < minPWM) pwmValue = minPWM;
    analogWrite(PWM, pwmValue);

    // Leer sensores VL53L0X y mostrar por Serial
    distVL1 = sensor1.readRangeContinuousMillimeters();
    distVL2 = sensor2.readRangeContinuousMillimeters();
    distVL3 = sensor3.readRangeContinuousMillimeters();

    Serial.print("Pulsos: "); Serial.print(encoderCount);
    Serial.print(" | Heading: "); Serial.print(heading);
    Serial.print(" | Servo: "); Serial.print(servo_angle);
    Serial.print(" | PWM: "); Serial.print(pwmValue);
    Serial.print(" | VL1: "); Serial.print(distVL1); Serial.print(" mm");
    Serial.print(" | VL2: "); Serial.print(distVL2); Serial.print(" mm");
    Serial.print(" | VL3: "); Serial.print(distVL3); Serial.println(" mm");

    last_error = error;
    delay(10);
  }

  // Detener motor y centrar servo
  analogWrite(PWM, 0);
  digitalWrite(MA1, LOW);
  digitalWrite(MA2, LOW);
  direccion.write(90);
}

void avanzarDespuesDeGiro(int pasos) {
  encoderCount = 0;
  sensors_event_t event;
  bno.getEvent(&event);
  float setpoint = facing;
  float last_error = 0, integral = 0;
  int maxPWM = 200, minPWM = 80;

  while (encoderCount < pasos) {
    bno.getEvent(&event);
    float heading = event.orientation.x;
    float error = heading - setpoint;
    if (error > 180) error -= 360;
    if (error < -180) error += 360;
    integral += error;
    float derivative = error - last_error;
    float correction = Kp * error + Ki * integral + Kd * derivative;
    int servo_angle = 85 - correction;
    if (servo_angle < 50) servo_angle = 50;
    if (servo_angle > 150) servo_angle = 150;
    direccion.write(servo_angle);

    int error_dist = pasos - encoderCount;
    int pwmValue = 0.5 * error_dist;
    if (pwmValue > maxPWM) pwmValue = maxPWM;
    if (pwmValue < minPWM) pwmValue = minPWM;
    analogWrite(PWM, pwmValue);
    digitalWrite(MA1, HIGH);
    digitalWrite(MA2, LOW);

    last_error = error;
    delay(10);
  }
  analogWrite(PWM, 0);
  digitalWrite(MA1, LOW);
  digitalWrite(MA2, LOW);
  direccion.write(90);
}
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

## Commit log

2025-09-05 Se subio el codigo del robot. Se agrego enlace al engineering Journal
2025-09-05 Archivo de esquematico de circuito agregado
2025-09-20 Improve README structure and add content to folders
    [Huskylens Cover_back.stl, Huskylens Cover_front.stl, Sizzling Rottis (6).stl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]
